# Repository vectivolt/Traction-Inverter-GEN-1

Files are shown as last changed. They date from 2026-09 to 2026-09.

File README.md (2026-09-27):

<p align="center">
  Traction Inverter GEN-1 — 220 kW · 800 V · SiC · ASIL-D-capable
</p>

<p align="center">
  
  
  
  
</p>
<p align="center">
  
  
  
  
  
  
  
  
  
  
  
</p>

<h3 align="center">
  A 220 kW-class SiC traction inverter for 500–850 V packs (800 V-class packs whose full-charge voltage stays ≤ 850 V) —<br/>
  engineered to be <b>economical</b>, <b>ASIL-D-capable</b>, and <b>buildable by any competent CEM</b>.
</h3>

<p align="center">
  <a href="#-schematics">Schematics</a> ·
  <a href="#-specifications">Specs</a> ·
  <a href="#%EF%B8%8F-system-architecture">Architecture</a> ·
  <a href="#-functional-safety-asil-d-concept">Safety</a> ·
  <a href="#-dc-link-discharge--checked">Discharge</a> ·
  <a href="#-bom--cost-analysis">BOM & Cost</a> ·
  <a href="#-manufacturing--sourcing">Manufacturing</a> ·
  <a href="#-verification-pipeline">Verification</a> ·
  <a href="#-getting-started">Build</a> ·
  <a href="#-roadmap">Roadmap</a>
</p>

---

## 🎯 What this is

**GEN-1** is a complete, netlist-verified schematic set + costed BOM for a four-assembly traction
inverter, generated from a single **tscircuit** source of truth:

> **Marine Series** (M8 · M10 propulsion cells, ferries to tugs) is a separate product line built
> on this design — see [`marine/README.md`](marine/README.md).

| Board | Domain | Contents | Parts |
|---|---|---|---|
| 🔴 **Power board** | HV (500–850 V) | 3× HIITIO `HCS600FH120D3C1` SiC half-bridges (EconoDUAL™ 3), 6× isolated gate-drive channels, dual gate-power flybacks, 2× isolated V<sub>DC</sub> senses, ASC buffer, HVIL loop | **274** |
| 🟡 **Cap bank** | HV (500–850 V) | Laminated-busbar assembly (not FR4 — it carries the 340 A bus): 16× 20 µF 1100 V film cans = 320 µF, entry lugs, 3× module DC tab pairs, discharge-board studs | **26** |
| 🟠 **Discharge board** | HV (500–850 V) | Bolt-on across the cap bank (XM3 pattern): always-on 66 kΩ passive bleeder + commanded active discharge (1.88 kΩ / 1200 V SiC), default-OFF opto control | **26** |
| 🔵 **Control card** | LV (KL30) | NXP **S32K396** lockstep MCU + **FS2633D** ASIL-D SBC, hardware gate-enable chain, ASC latch, resolver AFE, 3× hall-current AFE, 2× CAN-FD, vehicle interface | **219** |

### 🔗 Interboard links — every one explicit, both ends drawn + ERC-checked

| Link | Carries | Ends (sheet ⇄ sheet) | If it fails |
|---|---|---|---|
| **L1** 40-way harness | gate PWM ×6, faults/RDY, V<sub>DC</sub> + NTC feedbacks, EN/ASC, 15 V bias | `JIC` (power) ⇄ `JICC` (card) | every line default-OFF → gates held low |
| **L2** 4-way discharge link | V15 bias · `QDIS_CMD` · 2× GND | `JDIS` (power) ⇄ `JCTL` (discharge) | opto dark → active path OFF; 66 kΩ bleeder still discharges (57 s) |
| **L3** laminated busbar | DC bus (340 A<sub>rms</sub> class) | `JCBE*` lugs ⇄ HV entry · `JCB[UVW]*` tabs ⇄ module DC terminals · `JCBD*` studs ⇄ `JDCP/JDCN` (discharge) | bolted metal — torque-audited, HVIL opens the loop first |
| **L4** hall harness | 5 V per sensor + 3× current signals | `JLEM` (card) ⇄ 3× LEM HC5FW at the phase outputs | 100 k pull-downs (drawn since A.11): an open wire reads 0 V, outside the 0.2–4.8 V window → channel invalid |
| **L5** HVIL loop | interlock continuity through HV connector | `JHVIL` (power) ⇄ loop ⇄ card monitor | open = V<sub>DDIO</sub>/2 signature → controlled discharge |

Same net name on two sheets means **one net, joined only at the named connector/stud/tab** —
the rule is printed in every sheet's NET NAMING panel, and `erc-audit.mjs` asserts both ends
of every link pin-by-pin (the 40-way map alone is 80 assertions).
The design leans on three production references, read line-by-line: NXP **EV-INVERTERGEN3**
(control architecture, adopted almost verbatim), Wolfspeed **CRD300DA12E-XM3** (discharge +
gate-drive practice), and TI **TIDM-02014** (safety decomposition patterns).

> [!IMPORTANT]
> **Supply position:** the four power-silicon pieces (3 modules + discharge FET) come through
> a **direct HIITIO relationship**. Everything else on the BOM is LCSC-stocked or one
> ships-today DigiKey basket — verified line-by-line in two live sourcing sweeps.

---

## 📐 Schematics

The complete drawing set, one sheet per board — dashed functional sections, net-label-only
cross-section wiring, sheet index + net-naming + safety panels, self-identifying title blocks.

**➡️ Open the PDF set: [`boards/out-pdf/`](boards/out-pdf/) · Import into EasyEDA Pro: [`kicad5/Traction-Inverter-SHIP.zip`](kicad5/Traction-Inverter-SHIP.zip) · Open in native KiCad 5: [`kicad5/Traction-Inverter-KiCad5-native.zip`](kicad5/Traction-Inverter-KiCad5-native.zip) · Open in KiCad 10.0.6+ (the layout handoff: every symbol bound to a footprint in the shipped library): [`kicad/Traction-Inverter-KiCad-modern.zip`](kicad/Traction-Inverter-KiCad-modern.zip)** — three variants of the same sheets. EasyEDA's legacy importer ignores the symbol orientation matrix, so its variant carries a pre-mirrored library; native KiCad applies the matrix and needs the un-mirrored one (round 15, A13-R05); both are verified pin-by-pin with their consumer's placement rule. **Which KiCad reads which set:** the two legacy `.sch` sets are for KiCad 5–8; the `.kicad_sch` set ([`kicad/traction/`](kicad/traction/)) is for KiCad 10 (its schematics also open in KiCad 9, but the footprint library is the 10.0.6 file format, so the footprint-enabled handoff is KiCad 10 — round 23) — KiCad 10.0.6 loads the legacy sheets but resolves none of their symbols (its netlist has 0 components and its ERC flags every pin stub unconnected; its JSON report also prints each 200-mil stub as 0.0508 mm, which is 10.0.6 scaling every JSON coordinate by 1/100 for any schematic — the text report reads 5.08 mm). The `.kicad_sch` set is translated item for item from the same sheets and proved with KiCad 10.0.6 itself (`kicad-sch-verify.mjs`): ERC on every sheet, and a netlist export equal to circuit.json net by net.

| Sheet 1 — Power board (HV) | Sheet 4 — Control card (LV) |
|---|---|
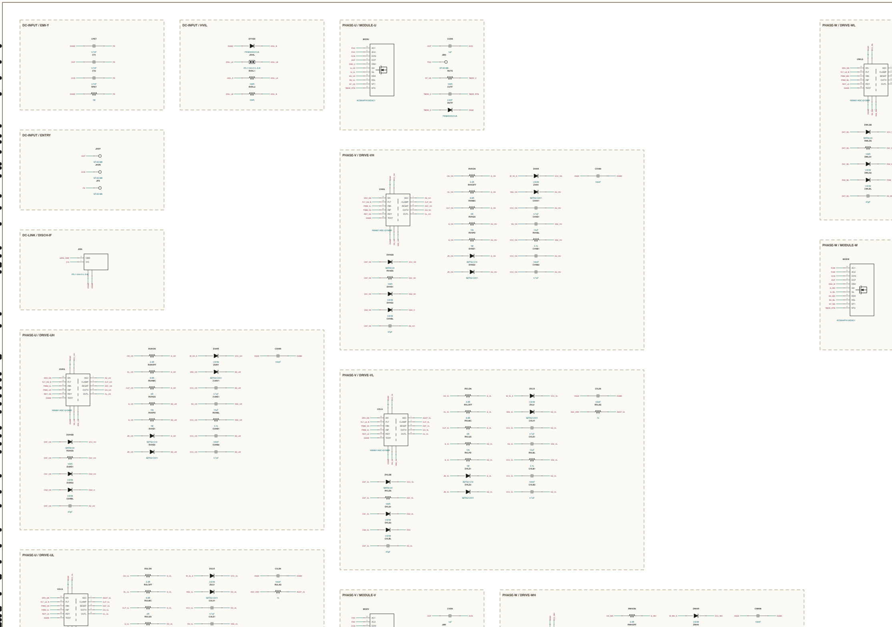
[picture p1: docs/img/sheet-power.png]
Power board sheet
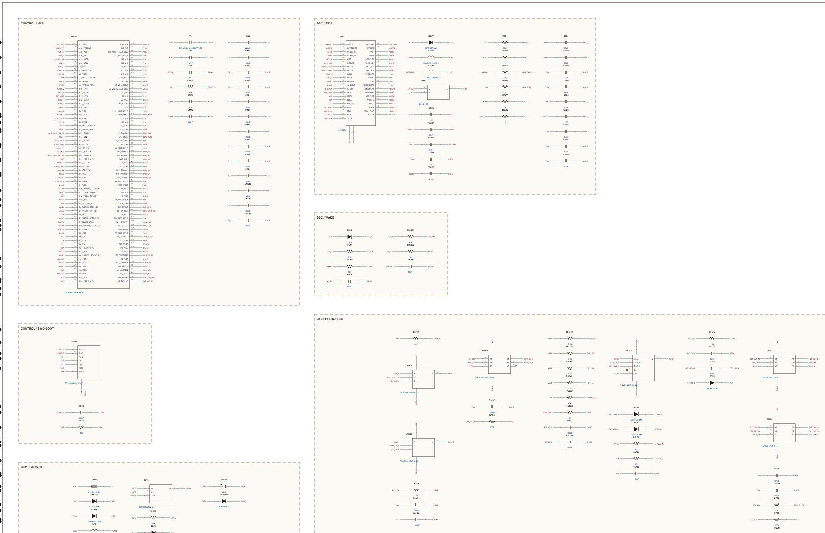
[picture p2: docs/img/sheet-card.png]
Control card sheet
|  |  |

| Sheet 2 — Cap bank (busbar assembly) | Sheet 3 — Discharge board (bolt-on) |
|---|---|
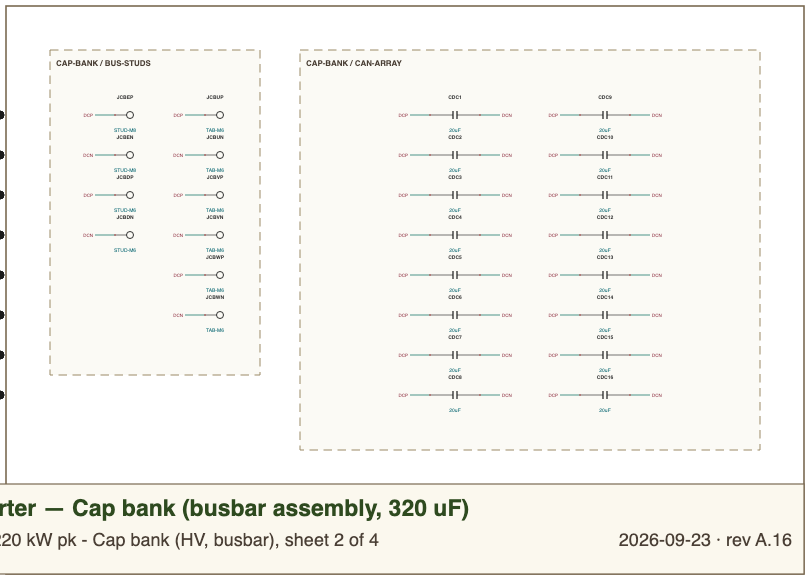
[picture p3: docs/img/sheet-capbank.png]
Cap bank sheet
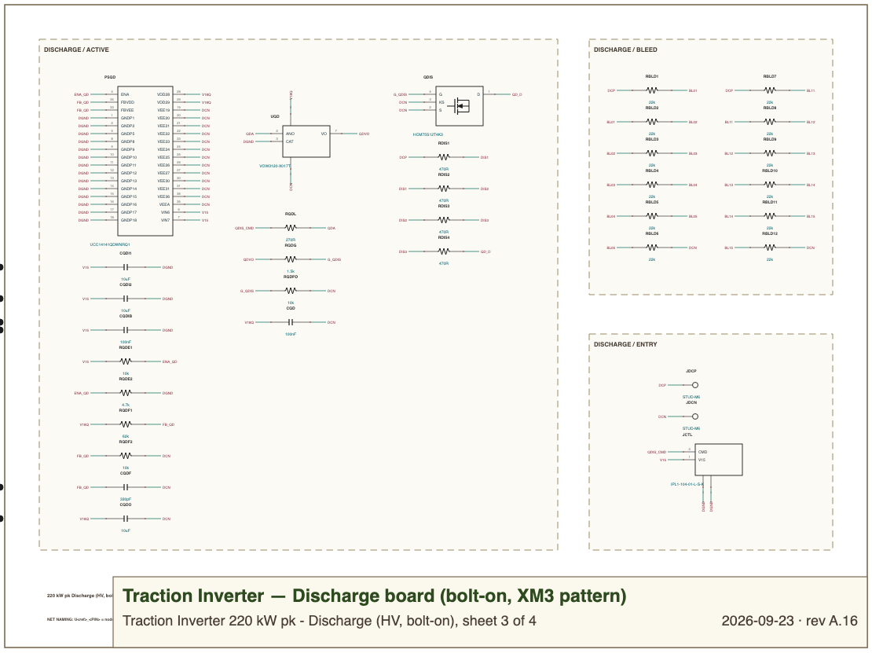
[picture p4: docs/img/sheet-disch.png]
Discharge board sheet
|  |  |

Every sheet carries its own review panels — the ASIL-D concept and the discharge verification
are printed **on the drawing**, so the schematic is never the only artifact a reviewer holds:

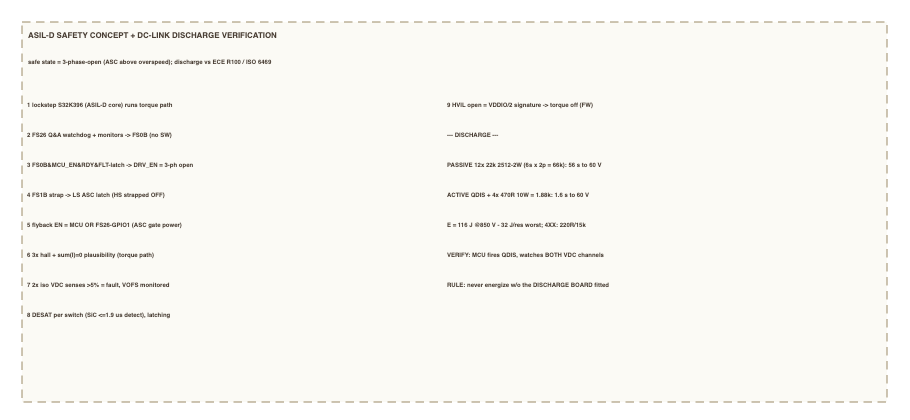
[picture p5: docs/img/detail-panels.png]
On-sheet panels: sheet index, net naming, ASIL-D safety concept + discharge verification


---

## ⚡ Specifications

<table>
<tr><td valign="top" width="50%">

### Ratings

| Parameter | Value |
|---|---|
| DC-link voltage | **500 – 850 V** (700 V nom) · 4XX SKUs **250 – 500 V** |
| Peak power | **220 kW** / 30 s from 654 V (168 kW at 500 V; 4XX 150 kW from 379 V) |
| Continuous power | **120 kW** from 656 V (4XX 90 kW) |
| Peak phase current | **340 A<sub>rms</sub>** (480 A pk) |
| Continuous phase current | 185 A<sub>rms</sub> |
| Semiconductor efficiency (continuous point) | **SiC 99.0 %** · **IGBT 98.6 %** |
| DC feed current | 314 A pk / 171 A cont |
| Switching frequency | **SiC** 8–10 kHz · **IGBT** 5 kHz |
| Motor type | 3-φ PMSM, resolver feedback |
| Cooling | Liquid coldplate @ 65 °C |
| Ambient | −40 … +85 °C |

</td><td valign="top" width="50%">

### Key silicon

| Function | Part | Grade |
|---|---|---|
| Power switch ×3 | HIITIO **HCS600FH120D3C1** (SiC) *or* **HCG600FH120D3E1EA** (IGBT) — same pads & pins | EconoDUAL 3 |
| Gate driver ×6 | **NSI6611A-Q1** 10 A iso, DESAT + Miller | AEC-Q100 |
| MCU | NXP **S32K396** lockstep M7 | ASIL-D |
| Safety SBC | NXP **FS2633D** | ASIL-D |
| V<sub>DC</sub> sense ×2 | **AMC1311B** reinforced iso | — |
| Phase current ×3 | LEM **HC5FW 900-S** hall | 900 A |
| Resolver driver | **ALM2402Q-Q1** | AEC-Q100 |
| CAN-FD ×2 | **TCAN1042HGV-Q1** | AEC-Q100 |

</td></tr>
</table>

<details>
<summary><b>📏 Sizing math (click to expand)</b> — why every number above closes</summary>

| Check | Calculation | Result |
|---|---|---|
| Max line-line voltage | V<sub>ll</sub> = 0.95 · V<sub>dc</sub>/√2 (linear SVPWM, 5 % reserve) | 470 V<sub>rms</sub> at 700 V |
| Power available | √(3/2) · 0.95 · V<sub>dc</sub> · 340 A · PF 0.85 | 235 kW at 700 V — 220 kW needs ≥ 654 V (FW-03) ✅ |
| Per-switch conduction, SiC peak | ½ · I<sub>rms</sub>² · R<sub>DS,hot</sub> = ½ · 340² · 5.7 mΩ (synchronous bridge) | 329 W |
| Per-switch switching + Q<sub>rr</sub> + dead time @850 V/10 kHz | DS energies at the drawn 3.3/6.8 Ω, ∝ V · I | 225 W |
| Per-switch total, 30 s peak / continuous | `loss-model.mjs` (SiC; IGBT build in `docs/variants.md`) | 554 W / 200 W → T<sub>j</sub> 125 °C (S4; 135 °C with no plate mass) / 90 °C ✅ |
| Voltage utilization | 850 V / 1200 V; turn-off overshoot is the DPT gate (S8) | 71 % ✅ |
| DC-link ripple current | I<sub>c,rms</sub> ≤ 0.65 · I<sub>ph</sub> (worst M/cosφ, Kolar) | 221 A pk (13.8 A/can) / 120 A cont |
| Link capability | 16 cans × 15.4 A (C3D, 10 kHz/70 °C) | 246 A ✅ |
| Stored energy @850 V | ½ · 320 µF · 850² | **116 J** |
| Gate power per switch (SiC) | Q<sub>g</sub> · ΔV · f = 1.09 µC · 20.5 V · 10 kHz | 0.22 W ✅ |
| Hall range | ±900 A vs 481 A pk | 1.9× headroom ✅ |

Full derivations: [`docs/design-basis.md`](docs/design-basis.md)

</details>

---

## 🏗️ System architecture

```mermaid
flowchart LR
  subgraph HV["🔴 POWER BOARD — HV domain"]
    direction TB
    DCIN["HV DC entry<br/>M8 studs + Y-caps + HVIL"] --> LINK["CAP BANK busbar assembly<br/>16× 20 µF/1100 V film = 320 µF"]
    LINK --> BLEED["Passive bleeder 66 kΩ<br/>57 s → 60 V"]
    LINK --> ADIS["Bolt-on discharge board<br/>66 kΩ bleeder · 1.88 kΩ + 1200 V SiC · 1.6 s"]
    LINK --> MU["MOD U<br/>600 A SiC ½-bridge"]
    LINK --> MV["MOD V<br/>600 A SiC ½-bridge"]
    LINK --> MW["MOD W<br/>600 A SiC ½-bridge"]
    GDU["2× NSI6611A-Q1<br/>DESAT · Miller · ±(15/−5.1) V"] --> MU
    GDV["2× NSI6611A-Q1"] --> MV
    GDW["2× NSI6611A-Q1"] --> MW
    FLY["2× gate-power flybacks<br/>UCC28C40 + 3× VGT12EEM each<br/>6 floating domains"] --> GDU & GDV & GDW
    VDC["2× AMC1311B iso V-sense<br/>independent dividers + bias"] -.-> LINK
    ASC["ASC buffer<br/>DCN-referenced opto"] --> GDU & GDV & GDW
  end

  subgraph LV["🔵 CONTROL CARD — LV domain"]
    direction TB
    SBC["FS2633D ASIL-D SBC<br/>VPRE·VCORE·VREF·LDOs<br/>Q&A watchdog · FS0B/FS1B"] --> MCU["S32K396<br/>lockstep M7 · eTPU · SWG · SDADC"]
    MCU --> SAFE["Hardware gate-enable chain<br/>FS0B ∧ MCU_EN ∧ RDY"]
    MCU --> RSLV["Resolver AFE<br/>SWG → MFB filter → ALM2402Q"]
    HALL["3× hall AFE<br/>LEM HC5FW 900-S"] --> MCU
    CAN["2× CAN-FD<br/>TCAN1042-Q1"] <--> MCU
  end

  MOTOR(("🌀 PMSM"))
  VEH["🚗 Vehicle<br/>KL30 · KL15 · CAN ×2<br/>resolver · motor temp"]

  MU & MV & MW ==>|"U · V · W<br/>340 Arms pk"| MOTOR
  SAFE -->|"40-way harness<br/>default-OFF"| GDU
  VEH <--> LV
  MOTOR -.->|resolver sin/cos| RSLV
```

<details>
<summary><b>🔌 One gate-drive channel in depth</b> (×6 on the board)</summary>

```mermaid
flowchart LR
  PWM["PWM_xH (IN+)<br/>PWM_xL (IN−)<br/>complementary pair =<br/>shoot-through lockout"] --> DRV
  EN["DRV_EN<br/>(hardware safety chain)"] --> DRV
  DRV["NSI6611A-Q1<br/>reinforced iso · 10 A"]
  DRV -->|"OUTH → 1.5 Ω"| G["Gate node"]
  DRV -->|"OUTL → 1.0 Ω"| G
  DRV -->|"CLAMP 0 Ω<br/>Miller clamp"| G
  G --> SW["SiC switch<br/>(½ of EconoDUAL)"]
  SW -->|"drain"| DS["DESAT chain<br/>BAT64-04 → 100 Ω → 2× US1M<br/>47 pF ≈ 1.5 µs blanking"]
  DS --> DRV
  BIAS["Flyback secondary<br/>rectifier + C5V1 zener split<br/>+15 V / −5.1 V vs Kelvin"] --> DRV
  DRV -->|"FLT# wired-OR · RDY wired-AND"| FB["→ MCU + safety chain"]
  G --- P1["10 k G-S bleed ·<br/>1 M HV pulldown at module pin ·<br/>18 V + 5V1 zener stack"]
```

Values carried from the GEN3/XM3 references; `R_g` tuned at double-pulse test.

</details>

---

## 🛡 Functional safety (ASIL-D concept)

The safe state is **3-phase-open**; above the motor's crossover speed it is **ASC** (active
short via the low side). The fast paths — watchdog → FS0B, DESAT → fault latch, the enable AND
chain, the ASC latch — are **hardware**; HVIL, V<sub>DC</sub> and ΣI plausibility are firmware
([`docs/firmware-contract.md`](docs/firmware-contract.md), including the fault × speed
safe-state matrix).

```mermaid
stateDiagram-v2
    direction LR
    [*] --> INIT : KL30 + KL15
    INIT --> RUN : FS26 WD happy · FS0B high<br/>MCU_EN high · RDY_HS ∧ RDY_LS
    RUN --> SPO : any of — WD fail → FS0B low ·<br/>DESAT latch · HVIL open ·<br/>VDC mismatch >5% · ΣI ≠ 0
    RUN --> ASC : overspeed + fault<br/>(MCU ASC_REQ or FS1B strap)
    SPO : SPO — 3-phase OPEN
    SPO : all 6 driver EN low (hardware AND)
    ASC : ASC — low-side SHORT
    ASC : latched · survives MCU reset ·<br/>SBC keeps gate power via GPIO1 OR-gate
    ASC --> SPO : speed below threshold · ASC_CLR
    SPO --> DISCHG : shutdown / crash / HVIL open
    DISCHG : ACTIVE DISCHARGE
    DISCHG : 850→60 V in 1.6 s · witnessed on BOTH V_DC channels
    DISCHG --> [*]
```

<details>
<summary><b>🔟 The ten hardware mechanisms (decomposition table)</b></summary>

| # | Mechanism | Independence argument |
|---|---|---|
| 1 | Lockstep **S32K396** (ASIL-D core) runs the torque path | — |
| 2 | **FS26 Q&A watchdog** + rail monitors → **FS0B** | Separate silicon, zero software |
| 3 | FS0B ∧ MCU_EN ∧ RDY **hardware AND** → all 6 driver enables | Discrete 74LVC1G11-Q100 gates |
| 4 | **FS1B strap → latched LS-ASC select** (HS strapped OFF) | SBC-commanded, survives MCU reset |
| 5 | Flyback enables **OR-gated (MCU ∨ FS26-GPIO1)** | SBC alone keeps gate power for ASC |
| 6 | 3× hall current + **ΣI = 0 plausibility** | 3rd channel = built-in redundancy |
| 7 | **2× isolated V<sub>DC</sub>** senses, >5 % ⇒ fault, shared offset monitored | Separate dividers, amps + bias; receivers share V5A, the ADC reference (monitored — A.6) |
| 8 | Per-switch **DESAT** (≤1.9 µs to detect on SiC, latching) → global latch delayed past the soft turn-off | Different technology vs halls |
| 9 | **HVIL** ladder — open = V<sub>DDIO</sub>/2 signature | MCU ADC (firmware, ≤100 ms) |
| 10 | **Default-OFF pulldowns** on every harness-floatable line | Passive |

> The architecture implements the NXP GEN3 / TI TIDM-02014 pattern. A formal ASIL-D *claim*
> additionally needs the ISO 26262 work products (HARA, FMEDA, DFA) — out of schematic scope;
> the hardware those analyses lean on is all present. In parts, the entire safety chain costs **₹37**.

</details>

---

## 🔻 DC-link discharge — checked

Both references ship only a passive bleeder; GEN-1 keeps that network **and** adds a
default-OFF active path for the ≤2 s crash case — then *verifies* it. The whole network rides
its own **bolt-on discharge board** (sheet 3 of 4) mounted across the cap-bank busbar
(sheet 2), the XM3 pattern: the stored energy and its bleeder are one assembly.

```mermaid
sequenceDiagram
    autonumber
    participant V as Vehicle / Crash signal
    participant M as S32K396
    participant Q as QDIS (1200 V SiC + 1.88 kΩ)
    participant C as DC link (320 µF · 116 J)
    participant S as V_DC senses ×2
    V->>M: shutdown / crash / HVIL open
    M->>Q: QDIS_CMD (opto, DCN-referenced, default-OFF)
    Q->>C: discharge @ τ = 0.60 s
    C-->>S: dV/dt on BOTH isolated channels
    S-->>M: 850 → 60 V in 1.6 s ✅
    Note over M,S: no dV/dt within 200 ms ⇒ stuck-off fault<br/>QDIS only with contactors open + 5 s timeout
    Note over C: passive 66 kΩ always fitted:<br/>57 s to 60 V with zero commands
```

| Path | Network | τ | 850 → 60 V | Stress per resistor |
|---|---|---|---|---|
| **Passive** (always on) | 12× 22 kΩ 2512 2 W, 6s×2p = 66 kΩ | 21.1 s | **56.5 s nom / 65.3 s worst** ✅ | 0.96 W (48 %) · 154 V worst-tolerance (77 % of 200 V) |
| **Active** (commanded) | 4× 470 Ω 10 W fail-open wirewound + SiC FET = 1.88 kΩ | 0.60 s | **1.57 s nom / 1.81 s worst** ✅ (≤2 s crash · 5 s R100) | 31 J worst pulse (≥100 J rated) · 213 V |

4XX SKUs use the same discharge PCB with 4 × 220 Ω and 12 × 15 kΩ (1.70 s / 88 s worst).

> [!WARNING]
> **Rule printed on sheet 1:** never energize without the passive bleeder network fitted.

---

## 📊 BOM & cost analysis

Four SKUs of the same boards, one parts-db (the sheets, BOMs and LCSC fields cannot
disagree, and every BOM fails if a printed value disagrees with its MPN) — platform and
business case: [`docs/variants.md`](docs/variants.md):

| SKU | Electronics BOM @1k | Ex-works unit | Per peak kW | Suggested price (35–40 % GM) |
|---|---|---|---|---|
| **8XX SiC** (HCS600) | **₹72,983** → [`bom.md`](docs/bom.md) | ≈ ₹1.17 L | ₹530/kW | ₹1.75–1.95 L |
| **8XX IGBT** (HCG600) | **₹47,483** → [`bom-igbt.md`](docs/bom-igbt.md) | ≈ ₹0.91 L | ₹415/kW | ₹1.35–1.55 L |
| **4XX IGBT** (HCG600, 150 kW) | **₹45,883** → [`bom-igbt4.md`](docs/bom-igbt4.md) | ≈ ₹0.92 L | ₹610/kW | per-kW for its segment |
| 4XX SiC (on request) | ₹71,383 → [`bom-sic4.md`](docs/bom-sic4.md) | ≈ ₹1.16 L | ₹775/kW | — |

602 components · 191 lines · zero unmatched · per-board CSVs alongside each BOM.

```mermaid
pie showData title Electronics BOM contribution (₹ @1k)
    "Modules 3× (SiC 54,000 / IGBT 28,500)" : 54000
    "DC-link film caps (16×)" : 4800
    "Hall sensors + AFE" : 2321
    "Gate-power flybacks" : 2225
    "MCU + clock + debug" : 1465
    "Everything else (16 subsystems)" : 4872
```

**The Pareto is extreme by design:** 19 components carry 84 % of the cost — concentrated in
*quotable, second-sourced* lines — while the ~470-part long tail is LCSC-basic jellybeans.
The complete 6-channel isolated gate drive is ₹656; the whole ASIL-D safety chain is ₹37.

<details>
<summary><b>📈 Full subsystem Pareto (21 rows)</b></summary>

| Subsystem | ₹ @1k | Share | Cumulative | Parts |
|---|---|---|---|---|
| SiC power modules | 54,000 | 77.5 % | 77.5 % | 3 |
| DC-link film caps | 4,800 | 6.9 % | 84.4 % | 16 |
| Hall sensors + AFE | 2,321 | 3.3 % | 87.7 % | 34 |
| Gate-power flybacks | 2,225 | 3.2 % | 90.9 % | 63 |
| MCU + clock + debug | 1,465 | 2.1 % | 93.0 % | 22 |
| Vehicle connector + protection | 785 | 1.1 % | 94.1 % | 6 |
| Gate drivers + networks | 656 | 0.9 % | 95.1 % | 120 |
| Discharge (active + passive) | 630 | 0.9 % | 96.0 % | 21 |
| Module snubbers | 540 | 0.8 % | 96.8 % | 3 |
| FS26 SBC + LV input + wake | 527 | 0.8 % | 97.5 % | 27 |
| V<sub>DC</sub> iso sensing + bias | 340 | 0.5 % | 98.0 % | 21 |
| Resolver AFE | 269 | 0.4 % | 98.4 % | 48 |
| Harness + pulldowns | 246 | 0.4 % | 98.7 % | 17 |
| LV power (prot + LDO + boost) | 236 | 0.3 % | 99.1 % | 24 |
| HV entry / Y-caps / HVIL / studs | 188 | 0.3 % | 99.3 % | 14 |
| ASC buffer | 139 | 0.2 % | 99.5 % | 7 |
| CAN-FD ×2 | 132 | 0.2 % | 99.7 % | 14 |
| Temps (module/board/motor) | 82 | 0.1 % | 99.9 % | 24 |
| V<sub>DC</sub> receivers (card) | 61 | 0.1 % | 99.9 % | 12 |
| Safety chain (EN/ASC/ILK) | 37 | 0.1 % | 100.0 % | 21 |
| Module NTC routing | 4 | 0.0 % | 100.0 % | 9 |

</details>

### 💰 Full unit cost @1,000 units

```mermaid
pie showData title Ex-works unit cost — ₹114.6k baseline (₹ @1k)
    "Electronics BOM" : 69700
    "Housing (CNC Al + anodize)" : 8500
    "Coldplate (FSW liquid)" : 6000
    "Busbars (laminated DC + phase)" : 6000
    "PCBs + PCBA" : 8400
    "HV connectors + coolant QCs" : 5200
    "Assembly + EOL test + coat" : 3200
    "Seals/TIM/harness/fasteners" : 3200
    "Yield + warranty 3%" : 3300
```

| | Low | **Baseline** | High |
|---|---|---|---|
| Ex-works cost / unit | ₹99.9k | **₹114.6k (~$1,380)** | ₹150.9k |
| ₹/kW | 454 | **521 ($6.3/kW)** | 686 |
| 1,000-unit build | ₹10.0 Cr | **₹11.5 Cr** | ₹15.1 Cr |
| Suggested ex-works price (35–40 % GM) | | **₹1.75–1.95 L (~$2,200)** | |

The two lines that move everything: the **HIITIO module quote** (47 % of unit cost) and the
**film-cap quote**. Comparable imported units (Cascadia CM350 class) sell at $4,000–7,000.
Detail + NRE table: [`docs/cost-rollup.md`](docs/cost-rollup.md)

---

## 🏭 Manufacturing & sourcing

Rev A.2 was a dedicated DFM pass, driven by **two live sourcing sweeps** (every specific MPN
checked on LCSC; misses re-checked on DigiKey/Mouser with LCSC alternates). Result — five
sourcing tiers, nothing single-channel outside the anchors:

| Tier | What | Lines | Channel |
|---|---|---|---|
| 🤝 **T1 Direct** | 3× SiC module + discharge FET | 4 | HIITIO (relationship in place) |
| 🏛 **T2 Franchise** | S32K396 · FS2633D · 3× LEM hall | 5 | NXP/LEM — **order first, longest lead** |
| 📦 **T3 DigiKey ships-today** | VGT12EEM ×6 · TE 770669-1/770680-1 · 10 W wirewounds · Murata MGJ2 ×2 (PO cert gate) · Coilcraft XAL ×3 · BUK7Y14-80E ×2 · NCV4276C ×3… | ~20 | one consolidated order |
| ✅ **T4 LCSC-verified** | ~60 lines *with live C-numbers* — incl. automotive grades of NSI6611A-Q1, AMC1311B, ALM2402Q-Q1, TCAN1042-Q1, TPS55340-Q1, OPA348-Q1, 74LVC1G11-Q100H, Faratronic link caps | ~60 | LCSC / JLC |
| 🧂 **T5 Jellybeans** | 0603+ passives, zeners, SS34, 2N7002… | ~440 | LCSC basic |

```mermaid
flowchart LR
  A["SMT 3 PCBs<br/>~750 placements · AOI"] --> B["Selective/wave THT<br/>studs · xfmrs · TO-247 · axials"]
  B --> C["Conformal coat card"]
  C --> D["CAP-BANK assembly<br/>16 cans onto laminated busbar"]
  C --> E["Modules → coldplate<br/>torque + TIM verify"]
  E --> F["Power PCB onto module pins<br/>(solder/press-fit per HIITIO dwg)"]
  D --> G["Busbar → module DC tabs<br/>+ DISCHARGE BOARD bolted across"]
  F --> G
  G --> H["Harnesses · lid · seal"]
  H --> I["EOL: hi-pot · discharge-time ·<br/>LV functional · B2B spin test"]
```

<details>
<summary><b>🔧 The seven DFM design changes (running log)</b></summary>

| # | Change | Why | Effect |
|---|---|---|---|
| 1 | Flyback controller **NJW4140 → UCC28C40DR** + 2-transistor default-OFF enable clamp | Nisshinbo part had 0–2 pcs on LCSC; the C43 grade cannot start at 9 V crank (F31) | Also **caught a latent bug**: the aux-only VCC could never start — trickle-start added |
| 2 | DC link **8× 40 µF → 16× Faratronic 20 µF/1100 V** (C2840809) | No 40 µF/1100 V can exists on LCSC in any brand | **−₹2.8k**, better ripple spread; TDK B32778 stays drop-in alt |
| 3 | Bleeder **9× TE CRGP (500 V specialty) → 12× generic 22 k 2512 2 W** 6s×2p (66 kΩ; the first cut, 10× 27 k 5s×2p, put 92 % of a 2512's 200 V working on each part) | TE part is TTI-only in volume | 154 V/resistor = 77 % of the 200 V working — any vendor builds it (dfm.md §2 item 3; boards/discharge.tsx RBLD1–12) |
| 4 | Resolver driver **confirmed ALM2402Q-Q1** (LCSC C544754) | Sweep found the GEN3-exact part in stock | No redesign |
| 5 | **Value consolidation** 4.99k→5.1k · 49.9k→51k · 12.1k→12k · 0402→0603 | Fewer feeders, JLC-basic, easier rework | Firmware-calibrated scalings unaffected |
| 6 | Vehicle connector → **TE 770669-1** 23-pos AMPSEAL header + 770680-1 plug | 776231-1 turned out to be the **35-pos** header (its own TE drawing, F60) | DigiKey-stocked, sealed automotive |
| 7 | Flyback switch **BUK9Y14 → BUK7Y14-80E**; clamp TVS SMAJ13A; both 10 µH → one XAL4040-103 line | Logic-level ±10 V gate was illegal at the 11.8 V drive (F56) | Same LFPAK56; zener now dark in normal operation |

Full plan incl. layout-phase DFM rules and proto-vs-production grade policy: [`docs/dfm.md`](docs/dfm.md)

</details>

---

## 🔬 Verification pipeline

Everything on this repo is **generated and gated** — the drawing set ships only at 100 %.

```mermaid
flowchart LR
  TSX["boards/*.tsx<br/>tscircuit source of truth"] -->|tsci build| CJ["circuit.json<br/>netlists"]
  CJ -->|pages.mjs| PG["section payloads<br/>21 functional pages"]
  PG -->|kicad5-gen.mjs| SCH["KiCad-5 sheets + lib<br/>skyline-packed sections,<br/>panels, title blocks"]
  SCH -->|kicad5-verify.mjs| V{"geometric re-derivation<br/>vs design intent"}
  SCH -->|kicad-sch-gen.mjs| KS[".kicad_sch set<br/>(KiCad 10)"]
  KS -->|"kicad-sch-verify.mjs<br/>(kicad-cli ERC + netlist)"| KV{"KiCad's own netlist<br/>vs circuit.json"}
  KV -->|"684 parts · 422 nets<br/>0 differences"| OK
  KV -->|any difference| FAIL
  V -->|"1717/1717 pins · 0 overlaps<br/>0 floating labels"| OK["✅ gate"]
  V -->|any mismatch| FAIL["❌ exit 1"]
  OK -->|kicad5-print.mjs| SVG["print-grade SVG"]
  SVG -->|"sheets-to-pdf.mjs<br/>(headless Chrome)"| PDF["📄 PDF set"]
  CJ -->|bom-gen.mjs| BOM["📋 bom.md + CSVs<br/>same parts-db as the sheets"]
```

Four independent verification layers — each with its own tool, none trusting the others:

| Layer | Tool | What it proves | Result |
|---|---|---|---|
| Sheets ⇄ netlist (geometry) | `kicad5-verify.mjs` | every drawn pin lands on its intended net — in BOTH shipped variants, each with its consumer's placement rule (EasyEDA import: raw offset; native KiCad 5: orientation matrix applied) | **2057/2057 · 100 % × 2** (the MCU by physical ball since A.13; ball-number and matrix mutations detected) |
| Sheets ⇄ KiCad (the tool itself) | `kicad-sch-verify.mjs` + KiCad 10.0.6 `kicad-cli` | the `.kicad_sch` set as KiCad reads it: ERC on every board sheet and the root (no dangling label or wire end, no unconnected pin, every symbol resolved, no duplicate reference); KiCad's exported netlist equals circuit.json — same components, same net names, same REF.pin in every net, the MCU on its manifest balls | **684/684 components · 422/422 nets · 0 differences** (a mirrored MCU — ERC-clean in KiCad! —, two swapped balls, the legacy harness numbering and a duplicated reference all detected) |
| Netlist ⇄ intent (structure) | `erc-audit.mjs` | pairing, chain topology, polarity, rails, floats, a lock-in per fixed finding | **954 checks · 0 fail** |
| Numbers ⇄ physics (worst case) | `design-verify.mjs` + `loss-model.mjs` | losses, thermal, envelope, discharge, protection timing, tolerances — **every SKU** | **132 PASS · 24 WARN · 0 FAIL** (each WARN names its bench/vendor gate) |
| Circuits ⇄ time/frequency domain | `sim-verify.mjs` | S1–S10: flyback start-up (cycle-by-cycle), boost Bode, SVPWM ripple, 30 s thermal per SKU, discharge ODE, current-loop PM per f_sw, overshoot budget, DESAT timeline, ASC hold-up | **23 PASS · 6 WARN · 0 FAIL** → [simulation-report](docs/simulation-report.md) |
| BOM ⇄ netlist (values) | `bom-gen.mjs` | every class MPN encodes the value the BOM prints; nothing is published unless the whole set validates | **0 mismatches, 4 SKUs** |

### 🔍 The review campaign — eight external rounds, every claim verified at the source

An independent reviewer ran five adversarial rounds against the released PDFs. The working
rule throughout: **no fix without primary-source verification, no rebuttal without evidence**
— every claim was checked against the manufacturer datasheet (winding diagrams read at
300 dpi where the dots decided it) before a single edit. Findings log **F1–F134, all closed**;
each round's full narrative lives in [`docs/design-basis.md`](docs/design-basis.md) §11.
Round six (46 findings) is answered line by line in
[`docs/review-A6-disposition.md`](docs/review-A6-disposition.md), and round seven (24 findings)
in [`docs/review-A7-disposition.md`](docs/review-A7-disposition.md), round eight (12 findings plus a 23-item cross-check of the fixes) in
[`docs/review-A8-disposition.md`](docs/review-A8-disposition.md), round nine in
[`docs/review-A9-disposition.md`](docs/review-A9-disposition.md), and the A.9 schematic rechecks, with their round-11 closure, in
[`docs/review-A10-disposition.md`](docs/review-A10-disposition.md), round twelve (63 findings across two
whole-system reviews) in [`docs/review-A11-disposition.md`](docs/review-A11-disposition.md), and the round-13
rechecks with the production closure (MCU ball map, barrier parts, connector) in
[`docs/review-A12-disposition.md`](docs/review-A12-disposition.md), and round fourteen (three reviews of the A.12
push: the pin-freeze errors, the firmware sequencing/clock/retention defects, the analog terminal-fault paths) in
[`docs/review-A13-disposition.md`](docs/review-A13-disposition.md), and round fifteen (three rechecks of A.13: the
exciter clamp topology, the native-KiCad export convention, the low-speed contactor loss) in
[`docs/review-A14-disposition.md`](docs/review-A14-disposition.md), and round sixteen (three rechecks of A.14: the
exciter amplitude corners and planes, the fault-model interpretation, the acquisition contracts) in
[`docs/review-A15-disposition.md`](docs/review-A15-disposition.md). Every contested number was
recomputed by an independent second model.

| Round | Release | Fixed | The headline catches |
|---|---|---|---|
| Self campaign | A.3 | 18 defects (F1–F36) | a gate supply that could never start; ASC drive over the driver's GND2+6 V abs max; discharge string missing the crash corner |
| Review 1 | A.4 | 10 (F37–F46) | **transformer secondary phasing** (forward-mode ≈35 V into +22 V-abs gates), DESAT clamp direction, raw KL15 into the MCU, unsourced gate-power feeds, hardware fault latch added, every symbol rebound to real package pins |
| Review 2 | A.4.1 | 5 (F47–F51) | **AMC1311 IN/SHTDN swapped on both channels** (inputs grounded), FS26 TRKIN was the VREF supply — not a ground-able spare, TPS55340 pin 5 is SYNC (7 V abs), V15 post-regulator vs boost pass-through |
| Review 3 | A.4.2 | 6 (F52–F57) | FS26 buck passives to Table-106, **CAN chokes wound 1-4/2-3** (CANH crossed onto CANL), ALM2402 behind its own LDO, **BUK7Y14-80E** (±20 V gate) |
| Review 4 | A.4.3 | 2 (F58–F59) | LCOR value/MPN/BOM/OTP agreement, UB15 compensation network (was ~0° screening margin) |
| Review 5 | A.4.4 | procurement | real MPNs bound; **RECOM R15P05S rejected** — 6.4 kV is a 1 s test, insulation grade *basic*; FS26 OTP table pinned (§8a) |
| Docs audit | A.5 | 3 (F60–F62) | JVEH rebound to the true 23-pos AMPSEAL **770669-1** (the TE drawing proved 776231-1 is 35-pos); QA01C rails read as **+20/−4 V** (the base part's sheet — corrected to the fitted QA01C-18, +18/−3 V, in A.9) — clamps re-verified |
| Review 6 | A.6 | 14 (F63–F76) | S8 overshoot **1000× unit error** (SiC turn-off now 6.8 Ω, DPT-gated); SiC conduction formula 2.4× low; IGBT SC is **6 µs** not 10 (blanking 82 pF); gate supply **never started at 9 V** (0.4 V UVLO hysteresis — 47 µF + 18 V clamp); BOM MPNs that would have re-created F40/F52; proposed "fault-dominant latch" **rejected** (deadlocks the NSI6611 FLT reset) — one-shot clear + soft-off delay instead |
| Review 7 | A.7 | 13 (F77–F89) | RC timing nodes into non-Schmitt LVC inputs at **63,500 ns/V** (Schmitt buffer); **ASC entry had no break-before-make** (12 nF LS delay; the MCU path holds ASC as PWM-ASC with EN high, because the NSI6611 honours DESAT over ASC only then — found by the round's own cross-check); flyback **locked out at high KL30** (own sense rectifier); FS1B loaded past its V_OL and FAULT_OUT made sink-only; 25 V caps on a 33 V node; ASC opto under its guaranteed turn-on current (self-found); +₹57/unit |
| Review 8 | A.8 | 16 (F90–F105, incl. its cross-check) | **a DESAT during latched ASC left the healthy low sides on** — the faulted driver holds itself off (NSI6611 Fig. 8.11) but only a ₹5 AND gate (ASC = latch AND no-FLT) guarantees SPO on every path; last slow latch preset buffered (FLT diode-OR now Schottky for the Schmitt threshold); discharge opto under-driven like the ASC one; boot self-test masked by RDY; FAULT_OUT battery-short clamp moved off the logic rail; atomic BOM publish; S4 junction path made static. Cross-check of the fixes: FW-15 always clears ASC, FW-16 on measured no-HV conditions with FS_GPIO1 and FLT-injection steps, dead-buffer pulls, 261 Ω LEDs inside 10–15 mA, B5V6 clamp, discharge header V15-GND-CMD-GND, ERC locks by net and MPN; +₹18/unit |
| Review 9 | A.9 | 14 (F106–F119, incl. its cross-check) | **the ASC/discharge bias modules were modelled from the wrong datasheet** (QA01C-18 is +18/−3 V, not +20/−4 V) — timing re-derived, discharge gate given a 1.5 k divider; **FLT/RDY pulled above the drivers' VCC1 rating** — pull-ups moved to V5GD on a harness pin; self-test energy-limited; RFS4 made anti-surge; self-found **≈150 mA parking drain** removed with one card-side P-FET. Cross-check of the fixes: V5GD read on an ADC pin (a dead V5GD faked a 0 V bus), harness re-laid for both dual-row numberings, resolver LDO sleeps too, QLVS slew-limited, DESATs kept in NVM; +₹29/unit |
| Review 10 | A.10 | 3 (F120–F122) | schematic-only rechecks of A.9 kept every correction; **RDY lines drove the AND gates at 20–100 ns/V against a 10 ns/V limit** — third Schmitt buffer (reverses a round-7/8 rejection); RASCG given a 0.33 W part; sheet and wording fixes; +₹11/unit |
| Review 16 | A.15 | 7 (F167–F173) | three rechecks of the A.14 push — all right: the SWG low corner through the series losses gave 6.34 V pp at the winding (exciter gain raised, 24 k → 28 k; FW-10 setpoint 7.2 V pp defined at the monitor plane with SWG-headroom and slew checks; planes documented); the back-drive row had read one RC time constant as the end of the pulse (exponential model, OPEN pending the diode envelope); **the exciter TVS is now unidirectional (SMCJ8.5A)** so a negative fault is carried by its forward diode instead of the amplifier's; the TVS-energy PASS rested on an extrapolated 20 ms allowance (conditional now, source impedance ≥ 0.27 Ω to allocate); the /33X PTC holds 70 mA at 85 °C (not 90); **firmware:** failed phase-ADC triplets stamped an uninitialised timestamp, resolver validity never expired without new blocks, and one SIN-DMA heartbeat tagged all three SDADC channels fresh — deterministic acquisition contracts, a per-tick frame-age policy and a coherent-frame API Same round, on instruction: the BOM furnished — every timing/filter/rail capacitor bound to a dielectric/voltage/size class, the last placeholders (KL15 polyfuse MF-MSMF010/60X, automotive beads, Samtec IPL1 link/HVIL headers, VY2 chassis cap) bound with archived sheets, and a drawn-size gate in the BOM generator. Marine forked at A.15 (86 PASS · 22 WARN · 0 FAIL). |
| Round 24 | A.23 | 3 (F240–F242) | **four rechecks of the A.22 push (`review-A23-disposition.md`), all three findings confirmed — one of them a wrong disposition of ours:** the S32K39 data sheet's SDADC table (Rev. 3 Table 38, in our archive and in our own extracted-parameters file) requires the SDADC reference within ±25 mV of its supply, and the round-23 row had judged the general +100 mV note and called the figure absent while the references sat on the FS26's separate VREF, matched to the SDADC-supply LDO only within ±1 % → every non-R2R reference group moved onto V5A itself, the node of VDDA_SDADC and VDD_HV_A (NXP's GEN3 arrangement), the ratiometric loads with it, the FS26 VREF kept for the R2R ladder alone with CSB5 2.2 µF holding its capacitance window by itself, the SAR's absolute scale re-budgeted at the LDO2's ±1.75 % (F240, no new part, a layout rule in the handoff); **firmware:** a stopped temperature ADC channel stayed valid forever because the caller discarded the acquisition timestamp → a three-state freshness contract (new / held / expired) with a hold-time CAL and the other slow consumers audited (F241); the inductance-map check bounded L but not the flux slope, and the ripple limiter looked only at its interval's ends → a positive flux slope required in every segment and the limiter evaluating the interior breakpoints, proved against a fine-scan oracle (F242); the R2R separation, the SMT SWD land, the torque solver (two independent fixtures: 8 four-quadrant cases, 20 000- and 4 049-case screens, zero violations) and the BOM intro confirmed by the reviewers' own runs; two more firmware defects found and fixed on the way (F243 the temperature-rate latch overwritten by an open/short sample, F244 the V_DC channels' sticky expiry); 444 tests / 5199 checks / 0 failed, TI_FW_ID 0x0A0F0016, 82 DTCs; ₹0/unit |
| Round 23 | A.22 | 26 (F214–F239) | **three rechecks of the A.21 push, one carrying five findings we had never received:** the R2R (sine-wave DAC) reference sat on the shared VREF5 against the S32K39 data sheet's note 8 → its own RC-isolated branch at ball A9 (RR2R 10 Ω + 1 µF + 100 nF, ≈ ₹0.6; F214); the SWD header is a SURFACE-MOUNT Samtec FTSH -DV and was bound to a through-hole land → the drawn SMT land and a mounting-technology lock in the library generator (F215); the footprint library is KiCad 10.0.6 format and was wrongly mirrored into the KiCad 5 sets → KiCad 10 is the footprint-enabled handoff, the KiCad 5 / EasyEDA sets carry names only (F216); **firmware: the torque solver could return a current vector representing ≈ 2× the requested torque in field weakening on a salient motor (i_d deepened without recomputing i_q; the witness checked voltage only) → torque, voltage, current circle and demagnetisation solved together on the torque curve with a postcondition before every return, the applied torque reported in the status (INV_STATUS 20 B), 300 tests / 2802 checks / 0 failed at that point, 8 mutations caught (F217); the no-LUT MTPA fallback now converges (F218)**; the BOM intro follows the SKU (F219); the review's ± 25 mV reference-tracking figure is not in the archived data sheet — a verifier row (50 mV against the +100 mV window) and VR-34 to NXP close it, VR-35 asks for the R2R reference current (F220). **Also this round, on the user's instruction — the VESC program:** the VESC firmware and VESC Tool sources archived as GPL-3.0 reference only (`docs/reference/vesc/`), a two-sided feature matrix (`docs/firmware-vs-vesc.md`) whose ranked gaps were closed in the same round — FW-38 signed field update (Ed25519, anti-rollback, ISO-TP transfer), FW-39 interlocked motor self-commissioning, FW-40 UDS diagnostics (0x19/0x22/0x2A/0x14 over ISO 15765-2, 80 DTCs), FW-41 fault-triggered waveform capture, FW-42 overspeed, FW-43 run-time statistics, FW-44 key-on offset adoption — and a closed-loop simulator bridge that ran the firmware against a plant for the first time and found twelve defects (F221–F232: uncontrolled diode regeneration once the back-EMF passes the link below n_x, a temperature-rate check tripping on one ADC code, unslewed torque steps, six never-set DTCs, ASC chosen at 2 000 rpm after a resolver loss, the demodulator's time centre, the resolver debounce bypass, an NVM CRC blind to torn records …), all fixed with fail-before/pass-after tests; 402 tests / 4707 checks / 0 failed, TI_FW_ID 0x0A0F0015, CAL layout 3 (4 after the extension); and **Traction Tool** (`tool/`), an offline Qt 6 bench/service application with the simulator, replay and CAN transports — see `docs/tool-stack-decision.md`. **Extension ("why not done / implement them"):** the suite runs on the Cortex-M7 instruction set with the target compiler under QEMU (T-59; test-code defects the target compiler caught, host rounding matched to the target, the 64-bit divide out of every ISR path with a link-time guard — F235–F237); every commissioning routine proved against the bridge, which found the bridge never loading a committed record (F233); the CAN transport proved against the firmware over a virtual bus — it had no ISO-TP reassembly (F234) — and the FW-38 update end to end over both transports, which found a UDS escape frame every non-diagnostic service dropped (F238) and a bridge without a boot record (F239); matrix gaps 8 and 10 closed as capabilities (FW-45 saturation tables, FW-46 cogging feed-forward; the maps are dyno measurements T-57/T-58; CAL layout 4); the licence items closed (corresponding source shipped, Qt attributions generated); the root of trust reported (DID 0xFD23); the Firmware page transfers images; 421 tests / 4937 checks / 0 failed; ₹0.6/unit |
| Round 22 | A.21 | 5 (F209–F213) | **three rechecks of the A.20 push — all right, one MINOR of theirs — and the user's question: why is the schematic not furnished for PCB layout?** The reviewers' NOT READY verdicts are bench, target and vendor evidence that needs a built board; the circuit carried no open defect. What was unfurnished was the handoff: every KiCad symbol carried a bare package code and no footprint library shipped, so Update PCB from Schematic could not run for any of the 686 components — **closed: `traction.pretty` (45 patterns copied verbatim from KiCad 10.0.6 with provenance, 18 drawn from the archived datasheets — the EconoDUAL 3 module, UCC14141 DWN-36, AMC1311B DWV, VOW3120, VGT12EEM, Samtec IPL1 ×3, TE 770669-1, the Faratronic can, Bel 2410 fuse, TDK ACT45B, the SQP10 at its real 55.88 mm pitch, onsemi SMA flat-lead, Kyocera 2-pad crystal, the FS26 and ALM2402 lands, LEM HC5FW), `fp-lib-table` and per-board project files in every set and zip, F2 = `traction:<name>` on every on-board symbol (the LEM sensors off-board), the generator refuses an unbound part, the KiCad proof judges footprint links and every pin number on a pad** (F210); the proof and a datasheet pin audit of 31 part groups caught the NCV4276C regulators coded as 3-lead DPAKs (5-lead only, F211), the ALM2402 and TPS55340 thermal pads with no symbol pin (pins 15/17 on ground, F212) and the two-terminal crystal on a 4-pad pattern (F213); the QP §0.2 DUT/FW/VAL baseline and the last 0x0A0F0011 mentions brought to A.20+ / 0x0A0F0013, the README bleeder row, MCU ball count, VR-17, the RFS4 fault-hold row and the dfm fillet rule corrected (F209); **[`docs/layout-handoff.md`](docs/layout-handoff.md)** is the layout engineer's entry point; ₹0/unit |
| Round 21 | A.20 | 1 (F208) | **three rechecks of the A.19 push — all right, nothing on the circuit:** F205–F207 close in all three (the alternates in the emitted CSVs, the firmware ID, the firmware trees identical to A.18; the diversion figures reproduced independently — 9.02 V / 3.84 A / 34.8 A at 24 V, 36.1 A at 35 V, τ 59.9 µs, 0.231 mC; the 4XX discharge 1.47 s at 220 Ω against 3.07 s at 470 Ω); one MINOR documentation defect — gate ㉘ still quoted IR-16 ≥ 0.29 Ω for the 35 V double event where IR-16 says 0.37 Ω (42.6 A against 37.9 A at the cold corner) — confirmed and broader than reported: the same round-18 figure sat in QP-RX-04's own step-3 fixture instruction, and 8.5 V-era figures remained in the QP's post-trip pass criterion (0.6 / 0.3 / 1.5–3.8 W), its Marine cross-reference (5.2 / 8.3 W, the uncapped formula), QP-RX-05's rail figure, VR-33's envelope (4.8 A / 0.28 mC / ≤ 11 V), this gate's trickle and sweep resistances, the card comment and the RSX BOM description (4.8–4.9 A) — every live figure now reads the 7.0 V-class value from the shared model with the old one marked; ₹0/unit |
| Round 20 | A.19 | 3 (F205–F207) | **three rechecks of the A.18 push — all right, nothing on the circuit:** the resolver-origin and high-current findings close in all three; two BOM-metadata errors of ours corrected — the exciter TVS alternate still called the 8.5 V part "same electricals" after the class change (→ the plain SMDJ7.0A, the 8.5 V class excluded from the qualification) and the 4XX discharge row carried the 8XX 470 Ω alternate (→ SQP10AJB-220R; four 470 Ω would take 3.1 s to 60 V against 2 s) — each with an ERC lock; the target checklist's firmware ID brought to 0x0A0F0013; every 8.5 V-era figure re-derived from the shared model at the IR-16 allocations, including the back-drive row that was still evaluated at 0 / 0.29 Ω; ₹0/unit |
| Round 19 | A.18 | 4 (F199–F202) | **three rechecks of the A.17 push — all right, plus one of our own:** the PTC-current row had been evaluated at 24 V while IR-16 allowed 26 V (41.6 A cold at 26 V / 0.05 Ω) — every permitted voltage now, minima at the verifier's own 5 % margin, rounded up (IR-16 0.09 / 0.33 / 0.25 Ω — the 8.5 V-class interim values, superseded within the round); the ≥ 8 A TVS-energy PASS rested on an I⁻² trip-time law no sheet states — an explicit assumption and a WARN closed by the measured clearing waveform (QP-RX-04 step 2 release criterion, VR-16); the resolver ring had anchored its clock on the first completion callback, so an over-budget or constantly-late callback became the reference — **FW-35 rewritten: the origin is the SWG start on the microsecond timer**, every completion judged absolutely, resync from the clock with per-channel slot checks, a synchronized restart on ambiguity; the round-18 window row had printed 1–200 Ω for a criterion error (14–83 Ω at 24 V); the exciter fault model is one shared module, run for the **Marine port at the ship's voltages** — the kit's 12 V rail is the platform's worst sustained-short case (5.2–8.3 W in the TVS by the uncapped 8.5 V-class formula — 2.0–2.5 W at the 7.0 V class after F203/F204), a kit-loom requirement and QP-MA-11 carry it; **one zero-cost part change — TVSEP/TVSEN → SMDJ7.0A-HRA** (the Opus cross-check showed the coupled island cannot hold the 8.5 V class below 148–171 °C at a parked 12 V battery or the Marine rail, because the tripped PTC's trickle scales with V_BR/(V_S − V_BR); the 7.0 V class halves it and stays ≤ 132 °C coupled, keeps every dark condition with ≥ 2.4 V margin, and costs +0.043 Ω on each IR-16 allocation — 0.08 / 0.14 / 0.37 Ω, an OEM statement now needed at 24 V); 290 tests / 2705 checks / 0 failed in three build flavours, 108 failing on the pre-fix ring, 16 mutations caught, TI_FW_ID 0x0A0F0013; ₹0/unit |
| Round 18 | A.17 | 9 (F190–F198) | **three rechecks of the A.16 push — all right, two under-stated:** the diversion Schottky sat on the protected node so its charging loop bypassed the resistor its own model divided by (27–99 A instead of 5 A) — moved to the amplifier node, zero parts; **the generic diode cell numbered the anode as pin 1 on all 35 two-pin diodes** against the parts' pinning tables and KiCad's footprints — one shared cell, ERC-locked on every board; the NCV4276C 40 V output rating withdrawn as reverse-current evidence (release gate + VR-33); the exciter TVS/PTC rows recomputed at their worst corners (the 20 ms bound holds only for a direct short; the 9 J point is ≈ 5.3 J rectangular) and the cross-check's own finding — a sustained short to the normal battery with the ECU asleep leaves 1.5–3.8 W in the TVS after the PTC trips (8.5 V class; 0.9–1.7 W since round 19) — closed by a layout rule, a bench sweep, IR-42 and VR-17; RSX an anti-surge 0.5 W part; firmware: fresh samples no longer aged against the earlier ISR clock, cadence-locked resolver frames with a servicing deadline and self re-acquisition, the chain-latency sign, plus three self-found instances of the same class (task liveness, the FW-15 recovery timer, the PWM-ASC dead-time reference) — 278 tests / 2534 checks / 0 failed in three build flavours, 98 (+2) failing on the pre-fix tree, 16 mutations caught; +₹2/unit (the anti-surge RSX pair) |
| Round 17 | A.16 | 16 (F174–F189) | **gap closure** ("close all gaps", "feel free to upgrade") — every WARN/OPEN/TODO became a design change, a numbered interface requirement (IR-01…41), a vendor request with acceptance criteria (VR-01…32) or an executable procedure (92 QPs): rated back-drive diversion diodes, 3 kW AEC-Q101 exciter TVS, the LV entry re-designed as let-through for ISO 16750-2 test B (pulse 1 was avalanching the reverse Schottky, the 2023 26 V jump start opened the old TVS, the input polyfuse was undersized at 9 V), RFS4 1206, stale rows recomputed, the discharge resistor no-flame statement cited, a KiCad 9/10 set proved by KiCad 10's own netlist (which exposed a harness pin-numbering defect in the legacy sets), firmware: all 35 open contract items closed, FS26 watchdog cadence 2.0 ms (was at the window edge), ASC-exit release wait, FW-31/32/33, a 39-row silicon checklist; 104 datasheets. Marine forks at A.16 (86 PASS · 22 WARN · 0 FAIL; the M10 stuck-ON wording corrected to 103 W per resistor on the SQP no-flame statement) |
| Review 15 | A.14 | 8 (F159–F166) | three rechecks of the A.13 push — all right: **the round-14 exciter TVS sat on the connector node, so a harness fault fed it without passing through the PTC** (moved to the protected node, 2.2 Ω series resistor, monitor tap moved, ERC graph-cut check); the "no back-drive" argument did not cover VEXD absent/cranking or negative faults (modelled, bench gate ㉘ extended); the PTC was bound to 1206 (it is 1812; /33X variant, hot hold 0.09 A); NTC_A's new ball is a standard-class ADC input but the target map said precision (generator now emits the full triple); **the shipped KiCad files were the EasyEDA-import variant only — read in native KiCad the mirrored library put H5 on FLT_CLR_M** (a `traction-native/` variant is now generated and both are verified with their consumer's placement rule, matrix mutation detected); the contactor-loss detector ignored low speed and left torque permission for the same invocation (firmware). Marine forked at A.14 (86 PASS · 22 WARN · 0 FAIL) |
| Review 14 | A.13 | 16 (F143–F158) | three independent reviews of the A.12 push (24 + 8 + 7 findings) — all right: **the A.12 pin freeze had H5 (V15, 1.5 V) on the 5 V reference and J7 (the V25 regulator output) grounded**; the map is re-derived against NXP's own GEN3 net report (every supply ball and 164/165 ports agree; the four signals without a netlist cross-check moved to confirmed balls; the symbol now numbers pins by ball). **Firmware:** the DESAT ISR bypassed the 22–53 µs hardware delay (hold added for every caller), the ms clock wrapped wrongly after 71.6 min, keep_hv ignored the all-speed rule (b), placeholder fault routing and a readback posing as a lock — now an arming-evidence record keeps the gates inhibited until route, lock and validation records exist (fail closed); torque feasibility witness; stuck-on discharge detection. **Analog:** excitation monitor 18 k + C_AAF (3 mA unpowered), exciter TVS + PTC per line, motor-temp SMAJ5.0A + bound fuse, 47 Ω bias-LDO ballast for the production UCC12051-Q1 (80 mA). UCC14141-Q1 VDE certificate archived. Marine forked at A.13 (86 PASS · 22 WARN · 0 FAIL). Wording: 500–850 V, the 4XX AC-power envelope, safety work is engineering |
| Review 13 | A.12 | 8 (F135–F142) | rechecks of A.11: **the energy rule now applies at every speed**; resolver input bound with the MCU unpowered (12 k) and the SDADC's 220 pF C_AAF restored; verifier counts distinct assemblies; the fitted TPS55340-Q1 is 40 V abs (the 34 V "upgrade" premise was false); LDO thermal on the datasheet pad. **Production closure:** MCU ball map bound (the fabrication blocker, with seven port errors of the old list fixed), FS26 pins verified, reinforced optos (VOW3120) and biases (UCC14141-Q1) in place of the uncertified TLP152/QA01C-18, 40-way connector, 4XX can, Y-caps and discharge resistors bound to orderable MPNs; Marine forked at A.12 (86 PASS · 22 WARN · 0 FAIL); firmware delivered in `firmware/`; +₹1,269 |
| Review 12 | A.11 | 12 (F123–F134) | two whole-system reviews (28 + 35 findings): **SPO release rule missed the stored winding energy** (rule (a) now an energy inequality); **resolver exciter drawn with its MFB feedback swapped** (0.18 → 1.85 at 10 kHz); **the V_DC bias "MGJ2D150505SC" never existed** (UCC12050 per channel, V_IOWM 1697 VDC); Hall pull-downs drawn and the LEM drawn by terminal; resolver-pin short to KL30 limited to the MCU's 3 mA; **the LV-entry TVS as described conducted at a 24 V jump start** (24 V-stand-off -VR class bound, load-dump source resistance gated); ALM2402 package, NTC symbol, verifier guard, contract wording; −₹165/unit |
| Review 11 | A.10 | 0 (closure) | schematic-only rechecks of A.10 closed A9-S01, S9-01 and S9-02 and asked for no circuit change; leftover "13.4–18.1 V" wording corrected; ESR03 terminal-temperature limits added to the layout rules |

Three review claims were **rebutted with evidence** (900 V divider corner — system max is
850 V on a 0.1 % bottom leg; the GEN3-exact resolver monitor asymmetry; the discharge math —
it matches), and two review narratives were corrected in our own records at the reviewer's
insistence (CBOOT_PRE 100 nF was legal; VCC1 loss is a single-point failure whose outcome is
three-phase-open with ASC still commandable).

Full findings log + margin tables: [`docs/verification-report.md`](docs/verification-report.md).

| Metric | Power | Cap bank | Discharge | Card | Total |
|---|---|---|---|---|---|
| Components | 295 | 26 | 26 | 255 | **602** |
| Functional sections | 24 | 2 | 3 | 26 | 55 |
| Net labels / pin stubs | 813 | 42 | 59 | 803 | 1,717 |
| Sheet size | 44.6″ × 28.6″ | 8.1″ × 5.8″ | 11.1″ × 7.8″ | 44.6″ × 25.3″ | 4 sheets |

---

## 🔁 One platform, four SKUs — SiC or IGBT, 8XX or 4XX, same boards

The cap bank and discharge were already bolt-on assemblies, and the hiitio SiC (HCS600) and
IGBT (HCG600) modules share the D3 outline and 11-pin map — so **one power PCB, one control
card, one discharge PCB and one busbar drawing build every SKU**. A SKU is a module, a film-
can choice, a few values on existing pads, an identity resistor and a firmware parameter set.

| | 8XX SiC | 8XX IGBT | 4XX IGBT |
|---|---|---|---|
| Bus / f_sw | 500–850 V · 8–10 kHz | 500–850 V · 5 kHz | 250–500 V · 5 kHz |
| Peak / continuous | 220 / 120 kW (from 654 V) | 220 / 120 kW (from 654 V) | 150 / 90 kW (from 379 V) |
| Tj end of 30 s peak (S4; static-plate bound 135 / 142 / 133 °C) | 125 °C / 175 °C | 132 °C / 150 °C | 125 °C / 150 °C |
| Deltas vs SiC | — | module, DESAT 4.7 k/82 pF, gate 1.0/1.0 Ω, RT 8.2 k | as IGBT + 16 × 50 µF/600 V cans, discharge 220 Ω / 15 k |
| BOM @1k | ₹72,983 | ₹47,483 | ₹45,883 |

Recommendation (business case in [`docs/variants.md`](docs/variants.md)): lead with 8XX (same
hardware, best ₹/kW), make IGBT the volume SKU at both voltages, keep SiC as the premium 8XX,
bring up EVT-1 on the IGBT build. 220 kW at 400 V needs ≈560 A rms — a same-pin-map 900 A
module plus larger sensors and cap bank, not a new board. Generate: `npm run bom:all`.

---

## 🧪 Simulation — the drawn circuits at their operating points

`calculations/sim-verify.mjs` numerically simulates the released netlist's circuits in the
time and frequency domain on the shared loss model (`loss-model.mjs`). **23 PASS · 6 WARN ·
0 FAIL** — full table with per-row modeling assumptions: [`docs/simulation-report.md`](docs/simulation-report.md).

| # | Simulation | Key result (rev A.15) |
|---|---|---|
| S1 | Gate-power flyback: drain stress + **cycle-by-cycle start-up** | one burst to the rails in **73–240 ms** at KL30 9–14 V, every corner (FB now on its own aux rectifier — A6-R07); the A.5 values never started at 9 V |
| S2 | UB15 boost loop Bode (A.4.3 compensation) | f_c 1.9–2.5 kHz, **PM 72–75°** |
| S3 | DC-link ripple, center-aligned SVPWM, swept M/cosφ | worst **0.65·I**: 13.8 A/can at 340 A (15.4 A rating); 4XX 16.2 A/can (18 A) |
| S4 | 30 s thermal transient per SKU, from continuous steady state | **125 / 132 / 125 / 133 °C** (8XX SiC / 8XX IGBT / 4XX IGBT / 4XX SiC; IGBT and diode share the coldplate — RR07; junction and case taken static — R7-07; with no plate mass at all 135 / 142 / 133 / 143 °C, the 8XX IGBT a WARN until the thermal test — R8X-11) |
| S5 | Discharge ODE, bleeder counted once | **1.57 s nom / 1.81 s worst** (8XX), 1.70 s (4XX) |
| S6 | Current-loop phase margin per f_sw | ceilings **1.39 / 1.15 / 0.76 kHz** at 10 / 8 / 5 kHz |
| S7 | Gate peak current (DS §9.6) | SiC 3.1/2.5 A · IGBT 5.6/10 A vs the 10 A driver |
| S8 | SiC turn-off overshoot budget at 850 V/481 A (DS fall time) | 7.8 nH at 3.3 Ω cold → **13.6 nH at 6.8 Ω cold**, 22.9 nH hot — **DPT gate** |
| S9 | DESAT reaction, worst corners | SiC **3.1 µs** (tSC unpublished → vendor letter) · IGBT **4.8 µs at 400 mA / 10.1 µs at the 100 mA DS minimum** vs the 6 µs rating → release gate (RR04) |
| S10 | ASC hold-up through total LV loss | **0.5–3.1 ms** (was quoted 15 ms; round 7 starts the worst case at the 13.54 V low-corner rail) → sustained ASC requires KL30; motor rule in the contract |

| | |
|---|---|
| S1 | S2 |
| S4 | S5 |
| S8 | S10 |

<p align="center">SVPWM DC-link capacitor current simulation</p>

Hardware-only items are named per-row as bench gates (layout parasitics, core saturation,
SiC short-circuit withstand, EMI) — simulated claims and measured claims are never mixed.

---

## 🚀 Getting started

```bash
npm install
```

```bash
npm run build     # tscircuit netlists  → dist/boards/*/circuit.json
```

```bash
npm run sheets    # pages → footprint library → KiCad5 sheets → 100% pin-verify → KiCad 10 set → kicad-cli proof (footprints, pads per pin) → SVG → PDFs  (needs Chrome + KiCad 10.0.6+)
```

```bash
npm run bom       # docs/bom.md + per-board CSVs
```

### 📁 Repository map

| Path | What lives there |
|---|---|
| [`boards/power.tsx`](boards/power.tsx) · [`boards/capbank.tsx`](boards/capbank.tsx) · [`boards/discharge.tsx`](boards/discharge.tsx) · [`boards/control-card.tsx`](boards/control-card.tsx) | **Source of truth** — the four assembly netlists |
| [`packages/cells.tsx`](packages/cells.tsx) | Parameterized cells: gate-drive channel, flyback chain, iso V-sense, hall AFE, CAN, 40-way harness map |
| [`calculations/parts-db.mjs`](calculations/parts-db.mjs) | Designator→MPN/LCSC/price/alt database + on-sheet safety/discharge panel text |
| [`calculations/*.mjs`](calculations/) | The generator pipeline (pages · kicad5-gen · verify · kicad-sch-gen · kicad-sch-verify · print · pdf · bom) · `circuit-net.mjs` = the circuit.json netlist loader erc-audit and kicad-sch-verify share · `loss-model.mjs` = the one SKU table + loss model both verifiers use |
| [`boards/out-pdf/`](boards/out-pdf/) | 📄 Rendered PDF schematic set |
| [`kicad5/`](kicad5/) | `traction/` + `Traction-Inverter-SHIP.zip` = EasyEDA-Pro import variant · `traction-native/` + `Traction-Inverter-KiCad5-native.zip` = native KiCad 5 variant (round 15; both name every footprint in their F2 fields but ship no library — schematic and import sets, not the layout handoff) — both for KiCad 5–8 |
| [`kicad/`](kicad/) | `traction/` + `Traction-Inverter-KiCad-modern.zip` = the KiCad 10 `.kicad_sch` set (the schematics open in KiCad 9 too; the footprint library `traction.pretty` is the 10.0.6 format, so the footprint-enabled layout handoff is KiCad 10 — round 23): project, root with the four boards as sheet instances, every symbol embedded plus an identical project library; proved with `kicad-cli` (KiCad 10 resolves no symbol of the legacy sets) |
| [`docs/design-basis.md`](docs/design-basis.md) | Ratings, sizing math, safety concept, references |
| [`docs/dfm.md`](docs/dfm.md) | Manufacturability plan + sourcing tiers |
| [`docs/bom.md`](docs/bom.md) · [`bom-igbt.md`](docs/bom-igbt.md) · [`bom-igbt4.md`](docs/bom-igbt4.md) · [`bom-sic4.md`](docs/bom-sic4.md) | Generated BOMs, all four SKUs, with subsystem Pareto |
| [`docs/variants.md`](docs/variants.md) | The platform: four SKUs on one set of boards, economics, recommended launch path |
| [`firmware/`](firmware/README.md) | **Production firmware (rev A.23)** against the contract — round 24: a three-state acquisition-freshness contract for every slow ADC input (a stopped channel had stayed valid forever), the inductance map's flux-slope rule and the ripple limiter's exact piece bounds, the temperature-rate latch kept under an open/short sample, the V_DC channels' sticky expiry; round 23: the torque → current path solved jointly on the torque curve with a postcondition (FW-37) and the VESC gap closure — signed field update with anti-rollback over ISO-TP (FW-38), interlocked motor self-commissioning (FW-39), UDS diagnostics 0x19/0x22/0x2A/0x14 with 80 named DTCs (FW-40), fault-triggered waveform capture (FW-41), overspeed (FW-42), run-time statistics (FW-43), key-on offset adoption (FW-44) — plus the twelve defects the closed-loop simulator bridge found (F221–F232), and the extension: FW-45 saturation-dependent inductance tables and FW-46 cogging feed-forward (the maps are dyno measurements), the 64-bit divide out of every ISR path, the root of trust reported (DID 0xFD23), the UDS escape single frame accepted by every service; 444 tests / 5199 checks / 0 failed (host, −O2, ASan/UBSan, and the same suite on the Cortex-M7 under QEMU with the target compiler — `make qemu-test`), target-check 63 markers, TI_FW_ID 0x0A0F0016, CAL layout 4 (191 fields / 92 rows), 82 DTCs — safety state machine with fail-closed arming evidence, DESAT hold, monotonic clock, battery-path loss at any speed, fault manager, FS26 SBC, sensing (currents with stuck-channel detection, V_DC, resolver with cadence-locked frames; ADC map and schedule generated from the ball map), FOC, CAN-FD with E2E, discharge with stuck-on detection, NVM (CRC-32C slots, 64), four SKUs; the host simulation (`make test`, also ASan/UBSan and -O2) and the simulator bridge (`tool/bridge`, `make check`); traceability FW-01…FW-46 → tests; what still needs the target/HIL and the NXP RTD |
| [`docs/firmware-contract.md`](docs/firmware-contract.md) | Hardware → firmware contract: SKU identity, envelope, protection allocation, safe-state matrix, fault-latch recovery; §10d FW-34…FW-36 (round 18: sample freshness, resolver time base, latency sign) |
| [`docs/mcu-pin-manifest.md`](docs/mcu-pin-manifest.md) · [`calculations/mcu-ballmap.json`](calculations/mcu-ballmap.json) | **Pin freeze (rev A.12)**: every S32K396 ball, its function, our net; the seven port corrections found |
| [`docs/review-A15-disposition.md`](docs/review-A15-disposition.md) · [`.csv`](docs/review-A15-disposition.csv) | Review round 16 (three rechecks of A.14): exciter amplitude planes and gain, the unidirectional TVS, the conditional fault rows, the acquisition contracts |
| [`docs/review-A14-disposition.md`](docs/review-A14-disposition.md) · [`.csv`](docs/review-A14-disposition.csv) | Review round 15 (three rechecks of A.13): the exciter clamp topology, the native-KiCad variant, the PTC package, the ADC class, the low-speed contactor loss |
| [`docs/review-A13-disposition.md`](docs/review-A13-disposition.md) · [`.csv`](docs/review-A13-disposition.csv) | Review round 14 (three reviews of A.12): every finding classified, verified and dispositioned; the MCU map cross-checked against NXP's netlist |
| [`docs/review-A12-disposition.md`](docs/review-A12-disposition.md) · [`.csv`](docs/review-A12-disposition.csv) | Review round 13 (rechecks of A.11) and the production-closure register: MCU ball map, VOW3120 / UCC14141-Q1, connector, can, Y-caps, SQP10, Marine A.12, firmware |
| [`docs/review-A11-disposition.md`](docs/review-A11-disposition.md) · [`.csv`](docs/review-A11-disposition.csv) | Review round 12 (two whole-system reviews, 63 findings): every finding classified, verified and dispositioned |
| [`docs/review-A10-disposition.md`](docs/review-A10-disposition.md) · [`.csv`](docs/review-A10-disposition.csv) | Review round 10 (schematic rechecks of A.9) and its round-11 closure: every finding classified, verified and dispositioned |
| [`docs/review-A9-disposition.md`](docs/review-A9-disposition.md) · [`.csv`](docs/review-A9-disposition.csv) | Review round 9: every finding classified, verified and dispositioned |
| [`docs/review-A8-disposition.md`](docs/review-A8-disposition.md) · [`.csv`](docs/review-A8-disposition.csv) | Review round 8 and its cross-check: every finding classified, verified and dispositioned |
| [`docs/review-A7-disposition.md`](docs/review-A7-disposition.md) | Review round 7: every finding classified, verified and dispositioned |
| [`docs/review-A6-disposition.md`](docs/review-A6-disposition.md) | Review round 6: every finding classified, verified and dispositioned |
| [`docs/simulation-report.md`](docs/simulation-report.md) | Operating-point simulations (S1–S10) with waveform/Bode plots |
| [`docs/cost-rollup.md`](docs/cost-rollup.md) | Full unit cost + NRE + pricing guidance |
| [`docs/verification-report.md`](docs/verification-report.md) | **End-to-end verification**: findings log F1–F134, per-SKU margin tables, worst-case corners |
| [`docs/datasheets/`](docs/datasheets/) | Component datasheet pack (108 PDFs) + extracted parameters |
| [`docs/vendor-requests.md`](docs/vendor-requests.md) | **Vendor requests register** VR-01…VR-35 (round 23): every open vendor input as an exact question with the design condition, the acceptance criterion and the verifier row or gate it closes — HIITIO, NOVOSENSE, TDK, Faratronic, Murata, Bourns, Littelfuse, Diodes, Samtec, NXP, LEM, coldplate |
| [`docs/interface-requirements.md`](docs/interface-requirements.md) | **Vehicle / motor / harness interface requirements** IR-01…IR-42 (round 18): what the inverter assumes about the LV supply, the motor and resolver (data for the safe-state decision, Z_primary ≥ 60 Ω), the harness (exciter fault double event), the HV side, the coolant, the EOL steps and the single-vs-double-fault safety assumptions |
| [`docs/qualification-plan.md`](docs/qualification-plan.md) | **Qualification plan** (round 17): 92 executable procedures with fixtures, steps and numeric pass criteria for every gate, every WARN row, the simulation WARNs, the firmware silicon/HIL items and the EOL line (QP-PS/GD/SC/TH/LV/HV/RX/DS/SF/FW/FAI/EOL/MA) |
| [`docs/layout-handoff.md`](docs/layout-handoff.md) | **Layout handoff** (round 22): the layout engineer's entry point — the KiCad project with every symbol bound to a footprint in the shipped `traction.pretty` (standard patterns copied verbatim from KiCad 10, the module, isolators, transformer, connectors, can, fuse, choke, power resistor and crystal drawn from the archived datasheets — `traction.pretty/MANIFEST.md`), per-board project files, the layer/copper facts, the creepage basis (PD2/OVC II provisional), the placement and routing rules by block, the open decisions with their owners, and the first-article measurements the layout must keep possible |
| [`docs/firmware-vs-vesc.md`](docs/firmware-vs-vesc.md) | **Our firmware against the VESC firmware and VESC Tool** (round 23): a two-sided, evidence-cited feature and control matrix from the archived VESC sources (`docs/reference/vesc/`, GPL-3.0 reference copies — nothing linked or copied) — where VESC's breadth is real (sensorless observers, HFI, 12+ sensor drivers, self-commissioning wizards, a mature GUI), where ours is ahead (fail-closed arming evidence, hardware-only fast protection, the §6 safe-state framework, the postcondition-checked torque solve, E2E CAN, fail-closed calibration, traceability and the fault-injecting host simulation), and the ranked gap list that round 23 closes as FW-38 … FW-44 (signed firmware update with anti-rollback, interlocked motor self-commissioning, UDS fault-history/DTC export and telemetry, fault-triggered waveform capture, overspeed protection, run-time statistics, key-on offset refresh) |
| [`docs/tool-stack-decision.md`](docs/tool-stack-decision.md) · [`tool/`](tool/) | **Traction Tool** — the offline bench/service desktop application (round 23): Qt 6 / C++17 Widgets with Qwt plots (LGPL; no GPL chart modules) and Qt SerialBus for the CAN-FD adapters (`tool/qt/`), driving either a real inverter or the firmware's host simulation through the C bridge in `tool/bridge/` (`tool/PROTOCOL.md`); dashboard, live plots, controls with the firmware's own arming preconditions, the calibration parameter editor from `gen-params`, faults and alerts with a bug-report snapshot, analysis, terminal, firmware page. The decision record weighs Bun, Electron, Electrobun, Tauri and Qt honestly — the user chose Qt for maturity; after the extension: the signed update end to end over both transports, every commissioning routine including the inductance-map sweep and the ripple-map import, the CAN transport proved against the firmware over a virtual bus (`Tools ▸ Simulator on virtual CAN`), the root-of-trust banner, one UDS request at a time, the corresponding source and Qt's attributions shipped with the package (`scripts/licences.mjs`); 8 QtTest suites |

---

## 🗺 Roadmap

```mermaid
timeline
    title GEN-1 program
    section Done ✅
        Research : NXP GEN3 + Wolfspeed XM3 + TI TIDM-02014 read line-by-line : HIITIO catalog swept
        Rev A.1–A.3 : Schematic-complete set : DFM pass : verification campaign (F1–F36)
        Rev A.4–A.4.4 : Five external review rounds answered at the source (F37–F59) : real MPNs bound
        Rev A.5 : 4-assembly set · S1–S10 simulations · IGBT drop-in variant (HCG600, same pads) : F60–F62
        Rev A.6 : Review round 6 answered (46 findings) : F63–F76 · one platform, four SKUs (8XX/4XX × SiC/IGBT) : firmware contract
        Rev A.7 : Review round 7 answered (24 findings) : F77–F89 · ASC break-before-make in hardware · Schmitt-buffered safety logic · flyback lock-out fixed
        Rev A.8 : Review round 8 answered (12 findings + 23 cross-check items) : F90–F105 · a latched DESAT masks ASC on every path · every latch preset buffered · both optos inside 10–15 mA · FW-16 covers the FLT paths
        Rev A.9 : Review round 9 answered (6 findings + 2 gates + 15 cross-check items) : F106–F119 · QA01C-18 bound to its own sheet · FLT/RDY pull-ups on V5GD · FW-16 energy limit · no parking drain
        Rev A.10 : Schematic rechecks of A.9 answered : F120–F122 · RDY Schmitt-buffered · RASCG 0.33 W
        Rev A.11 : System review round 12 answered (63 findings) : F123–F134 · SPO energy rule · resolver MFB · UCC12050 bias · Hall pull-downs
        Rev A.12 : Rechecks + production closure : F135–F142 · MCU ball map bound · VOW3120 / UCC14141-Q1 barrier parts · connector, can, Y-caps, SQP10 bound · firmware/
        Rev A.13 : Round 14 (three reviews) : F143–F158 · H5/J7 fixed, map vs NXP netlist, ball pin numbers · firmware fail-closed arming, DESAT hold, clock, keep_hv · exciter/monitor/motor-temp protection · LDO ballast
        Rev A.14 : Round 15 (three rechecks) : F159–F164 · exciter TVS behind the PTC + 2.2 R · native-KiCad variant + matrix-aware verify · PTC 1812 · ADC class triple · contactor loss at any speed
        Rev A.15 : Round 16 (three rechecks) : F167–F173 · exciter gain 28 k + amplitude planes · unidirectional TVS · back-drive/TVS rows conditional · acquisition contracts (phase ADC, resolver age, coherent frames)
    section Next 🔜
        Pin freeze : DONE in A.12 — S32K396 289 balls bound from SPF-91122 + DS anchors : FS26 pins verified : connector bound
        RFQ : hiitio Ls + SiC SC letter + module quotes : Faratronic 4XX can : NOVOSENSE soft-off vs EN
        Layout : power-board floorplan around 3 modules : laminated busbar : card 6-layer
        Proto : EVT-1 on the IGBT build : SiC double-pulse at 850 V sets RG_OFF : SC tests : discharge timing : resolver loop
    section Then 🎯
        DVT : CISPR 25 EMC : ISO 16750 environmental : thermal endurance
        Production : casting tooling : EOL rig : 1k ramp @ ~₹1.15L (SiC) / ~₹0.90L (IGBT) per unit · 4XX IGBT ~₹0.92L
```

> [!NOTE]
> **⚠️ VERIFY-before-layout list (rev A.13)** — ① ~~S32K396 package and ball map~~ **closed in A.13** — the A.12
> freeze had two supply balls wrong (H5 = V15, J7 = V25; round 14); the map is now cross-checked ball by ball
> against NXP's GEN3 net report and every signal sits on a netlist-confirmed ball, the KiCad symbol numbers pins
> by ball ([`docs/mcu-pin-manifest.md`](docs/mcu-pin-manifest.md)); FS26 48 pins verified, connector bound · ② **SiC double-
> pulse at 850 V/481 A, cold and hot** sets RG_OFF (3.3–10 Ω; module Ls unpublished) ·
> ③ **short-circuit**: hiitio SiC letter, contained SC tests per silicon, NOVOSENSE statement on
> RST/EN during soft turn-off + I_STO spread · ④ coldplate Rth (0.045 K/W assumed) and can
> sharing · ⑤ bias bank at worst parts + VGT12EEM Isat/working insulation · ⑥ motor data for
> the safe-state matrix (and whether the HV backup bias is needed) · ⑦ FS26 OTP readback ·
> ⑧ ~~4XX can MPN~~ **bound in A.12** (Faratronic C3D1U506KFAA382; ripple rating checked at PO) · ⑨ LEM lead time — **order T2 parts at kickoff** · ⑩ LEM sign-off
> on the phase-busbar insulating sleeve (HC5FW/SP1 is the reduced-insulation variant, N7) · ⑪ ~~TLP152
> barrier rating~~ **closed in A.12**: both optos are Vishay VOW3120 (V_IORM 1414 Vpk, DIN EN 60747-5-5, CPG ≥ 10 mm; N8) ·
> ⑫ HIL then dyno: contactor opening under full regen. The FW-06 chain is ≤ 15.6 µs to the ASC
> request plus ≤ 7.6 µs ASC entry, a link peak of ≤ 906 V on 8XX (N9, RR06; UCC14141-Q1 low end, A.12).
> ⑬ LV-only gate-supply bench: six-domain VCC2 inside 13.5–17.0 V, from 9 to 16 V KL30 and at a
> 24 V jump start (A6-R06/R07).
> ⑭ ASC entry measured on all six V_GS, on every entry path (RR05).
> ⑮ Discharge-resistor fault-opening qualification (A6-R11).
> ⑯ ~~Confirm PTC25/PTC26 reach an eFlexPWM FAULT input~~ **closed in A.12**: R14/PTC25 = PWM_1_FAULT[2],
> P15/PTC26 = PWM_1_FAULT[0] — the same eFlexPWM_1 instance as the six outputs; every VDD_HV_A/B ball on V5A
> (`docs/mcu-pin-manifest.md`).
> ⑰ NOVOSENSE statement on DESAT during ASC with EN low (§8.12 marks it irrelevant); this
> decides the FS1B-ASC residual.
> ⑱ VOW3120 100 °C ambient vs the power-board interior; LED drive and timing at corners on both optos.
> ⑲ No-HV driver fixture: DESAT injected during PWM-ASC; the faulted gate must stay off and the
> healthy ones must release (UASCG) until an authorised reset (R7-01).
> ㉔ ~~Barrier working-voltage statements for the parts that only quote a hipot~~ **closed at BOM level in A.12**:
> PSASC/PSQD are TI UCC14141-Q1 (reinforced, V_IORM 1414 Vpk / V_IOWM 1000 Vrms, IEC 60747-17) and the Y-caps
> Vishay VY1 (Y1, 1500 VDC); what remains is the PO-time check that TI's VDE/UL certificates, listed "planned"
> in SLUSF10B §7.6, have issued (round 12, R1-F12; design-basis §6a). ㉕ Resolver bench: 8 V pp at 10 kHz from the SWG amplitude register against the
> excitation monitor, and the harness short-to-KL30 injection measured at the SDADC pins (R2-F04/F13).
> ㉖ Discharge resistor (re-scoped round 17): the no-flame property is closed on paper by the bound part's
> sheet — TT/Welwyn SQP "will not burn or emit incandescent particles under any condition of applied temperature
> or overload" (the Yageo alternate lacks the statement and is constrained in the BOM; VR-28) — so the ⑮
> stuck-ON test now only characterises the fail-open time (QP), it is no longer a release gate. ㉗ LV entry (re-scoped round 17): the entry is LET-THROUGH — every clamp stays dark at the 35 V test-B plateau
> (TPSMC33A-VR/TPSMC18A-VR anti-series pair at the pin ahead of the reverse Schottky, TPSMC33CA-VR on the power
> board), every downstream part is shown rated for it (FS26 36 V extended operation, boost 38/40 V, LDOs, flyback
> drain), a 100 µF hybrid capacitor absorbs pulse 2a and a 5 A fuse replaces the undersized polyfuse — closed on paper
> at every source impedance (F189); what remains is measured: QP-LV-02/03/04 (jump start, test B at the OEM's Ri, the
> other ISO 16750-2/7637-2 pulses) and the FS26 "limited period" duration asked of NXP (VR-29). Test A (unsuppressed
> dump) is not supported — IR-03 (central suppression, Us* ≤ 36 V at the pin).
> ⑳ FAULT_OUT wire-fault injection with V5A up, sleeping and off, a 35 V pulse, and FS1B asserted into
> the short (A7-N04, P-01).
> ㉑ V5GD-off state with the pull-ups on V5GD (A8-01): FLT/RDY low → SPO, nothing back-powers the dead domain.
> ㉒ FW-16 on HIL: skip/stored-pass rule, the FS_GPIO1 steps, FLT injection with the pad rule
> (R8X-02/03/17); motor commissioning: ASC-entry current vs the DESAT minimum (R8X-13).
> ㉓ Bias and gate levels (A8-N01/N02): UCC14141-Q1 output at no load/start-up/ON, QDIS V_GS, ASC entry at the low end.
> ㉙ Parking drain with the card in LPOFF (N17) and the self-test energy fixture at ≤ 13 V (A8-N03) (renumbered from a second ㉔ in round 17).
> ㉘ Terminal-fault bench (round 14, F04/F18; widened rounds 15–16; re-scoped round 17; two release gates restored
> round 18): each resolver excitation line and each motor-temperature line to 24 V/60 s and 35 V/400 ms with
> VEXD/the MCU on, off and cranking, positive and (where the OEM allocates it) negative. Characterisation for the
> sheet-bounded single fault (fault current ≥ 8 A — the ISO 16750-2 direct short: TVS energy ≤ 1.7 J against the
> exciter TVS's 5.3 J rectangular-equivalent — SMDJ7.0A-HRA since round 19 (F203) — PTC current ≤ 40 A at the IR-16 harness minimum), the PTC hold (IR-13)
> and the 35 V double event (IR-16 ≥ 0.37 Ω at 35 V since round 19 — round 18's 0.29 Ω was the 8.5 V-class figure and gives 42.6 A
> cold against the PTC's 40 A, 37.9 A at 0.37 Ω; round 21 F208 / IR-33). RELEASE GATES since round 18 (F191–F194): (a) QP-RX-05 — the
> reverse rail current into ULDOEX with its input at 0 V, cranking and inhibited: the diversion diodes DEXP/DEXN
> now sit on the amplifier node so the charging loop passes RSX (≈ 3.9 A / 60 µs with the 7.0 V clamp, judged by I²t), and the NCV4276C's
> 40 V output rating covers the node voltage only (VR-33); (b) QP-RX-04 step 2b — a sustained short through
> 0–100 Ω external at 12.6/14.4/16/24 V with the ECU asleep, where below 8 A the PTC's trip time is a typical curve
> and the tripped PTC's trickle leaves 0.9–1.7 W in the TVS at 12.6–16 V, 1.5–3.8 W with the 8.5 V class of round 18 (dfm.md: TVS copper island with the PTC thermally coupled
> on it; IR-42; VR-17). RSX is an anti-surge 0.5 W part (the powered negative fault). Since round 19 (F199/F200) the
> ≥ 8 A clearing measurement (trip ≤ 20 ms, ∫v·i ≤ 5.3 J at 0 / 0.14 / 0.5 / 1.33 Ω, 16 / 24 / 26 V) is a release criterion too —
> the sheet bounds only the 8 A point — and the Marine kit runs the same sweep at the ship's voltages (QP-MA-11: its
> 12 V rail is the platform's worst case). Measured for the record:
> PTC clearing waveform (cold, hot, post-trip), PTC/TVS/Schottky currents, the reverse rail current into
> ULDOEX, TVS temperature, buffer unharmed, excitation amplitude at the WINDING (≥ 6.5 V pp; the monitor plane is
> before the PTC) against the selected resolver's measured impedance; energy-limited source first (procedure in
> docs/qualification-plan.md). **Target evidence for the arming record** (F01/F02/F06):
> PWM-fault injection on PTC26/PTC25 with the CPU halted, the ADC-watchdog → PWM-fault chain ≤ 15.6 µs,
> REG_PROT lock readback, WCET — the firmware refuses to arm without it.
> Full list with owners: [`docs/review-A9-disposition.md`](docs/review-A9-disposition.md).

---

## 📚 References

| Source | What GEN-1 took from it |
|---|---|
| **NXP EV-INVERTERGEN3** (SPF-91122 / EV-POWEREVBHD2) | Control architecture near-verbatim: FS26 rails & FS0B/FS1B paths, OR-gated flyback enables, resolver AFE chain, hall AFE, PWM/PWMALT lockout, interlock signature |
| **Wolfspeed CRD300DA12E-XM3** (PRD-06975 + discharge PCB) | Passive-bleeder discharge numbers, gate-drive practice (±15/−4 rails, soft-shutdown, 2 µs dead-time guidance), DC-link class |
| **TI TIDM-02014** (TIDUF23A) | Safety decomposition: PMIC SAFE-OUT OR-gate, LVSS strap matrix concept, dual-path ASC authority |
| **HIITIO catalog** (hiitio.com, 2025 datasheets) | HCS600FH120D3C1 (SiC) + HCG600FH120D3E1EA (IGBT variant, same D3 pads/pins), HCM75S12T4K3; EconoDUAL 3 footprint strategy |

---

<p align="center">
  
  <br/>
  <sub><b>Traction Inverter GEN-1</b> · rev A.15 · one platform, four SKUs (8XX/4XX × SiC/IGBT) · schematic-complete, layout next.<br/>
  Proprietary — © Vectivolt. Reference designs cited remain property of their respective owners.</sub>
</p>

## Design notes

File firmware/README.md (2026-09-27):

# Traction inverter firmware (S32K396 + FS26)

This is the application firmware for the 220 kW / 850 V traction inverter. It covers four SKUs:
8XX SiC, 8XX IGBT, 4XX IGBT and 4XX SiC. It implements `docs/firmware-contract.md` (rev A.18),
§8/§8a of `docs/design-basis.md`, the round-12 disposition, the ball map
`calculations/mcu-ballmap.json`, the round-14 review of commit cfd35a7 (see "Round 14"), the
round-15 rechecks of commit a8c75eb (see "Round 15"), the round-16 rechecks of commit 32214be (see
"Round 16"), the round-17 closure of every open item (see "Round 17": each one is now a decision in the
contract or a row of the target checklist `docs/target-bringup.md`), the round-18 rechecks of commit 4425af9
(see "Round 18") and the round-19 rechecks of commit e315bf1 (see "Round 19"). It is C11 with no dynamic memory
and no recursion, and every loop is bounded. It uses fixed-width types and single-precision float only.

The Wolfspeed CRD200 package was used only to check which structure is usual for such a
firmware. No code was taken from it.

## Build and test

```
make test          # host build of the firmware + simulation + tests, then run (cc, warnings = errors)
make target-check  # syntax-check src/platform/s32k396 on the host with the RTD calls compiled out, and check
                   # that every TODO(<kind>) marker has its row in docs/target-bringup.md (and back)
make target        # S32K396 build: needs S32K3_RTD=<path> and arm-none-eabi-gcc (see Makefile)
make params        # regenerate include/params_<sku>.h + cal_ranges.h (node tools/gen-params.mjs)
make board-map     # regenerate src/platform/s32k396/board_pins.h from the ball map (node)
make qemu-test     # the same suite built by arm-none-eabi-gcc for the Cortex-M7, run on QEMU (below)
make target-size   # text/data/bss of src/ + the s32k396 platform for the M7 (RTD calls compiled out)
make clean
```

`make test` compiles with `-std=c11 -Wall -Wextra -Werror -Wshadow -Wdouble-promotion
-Wmissing-prototypes -Wstrict-prototypes -Wundef -Wpointer-arith -Wcast-qual -Wvla`. Test files
alone get `-Wno-double-promotion`, because their reference arithmetic is done in double. Current
result (round 24: F241, the slow channels' acquisition freshness, the FW-45/FW-46 review and the F243/F244 follow-ups): **443 tests, 5195 checks, 0 failures**, also with `-fsanitize=address,undefined` and at
`-O2` (`make BUILD=build/asan test CFLAGS="-O1 -g -fsanitize=address,undefined"`,
`make BUILD=build/o2 test CFLAGS=-O2`).

For the target build you need these, which are not in this repository:

- The NXP S32K3 RTD for S32K39x, with the IP drivers FlexPwm_Ip, Adc_Sar_Ip, Bctu_Ip, Sdadc_Ip,
  Dma_Ip, Trgmux_Ip, Lcu_Ip, Siul2_Port_Ip, Siul2_Dio_Ip, Lpspi_Ip, FlexCAN_Ip, Stm_Ip, Swt_Ip,
  Fee/Fls (C40), Fccu_Ip, Clock_Ip and IntCtrl_Ip.
- The S32K39 device headers.
- An S32 Config Tools project that generates the configuration symbols named in the RTD markers
  (`docs/target-bringup.md` lists every one).
- A linker script with two sections: `.ti_retained` (no-init, survives an MCU reset) and
  `.ti_nocache` (for the eDMA buffers).

The SKU is picked at build time with `SKU=TI_SKU_8XX_IGBT` or similar. At boot, HW_ID and the
calibration record must agree with it (FW-01/02/20).

**Arming is blocked until everything below is provisioned — fail closed, nothing is assumed.**
1. `cal_fs26_prog_id` = the M_PROGID of the FS26 OTP variant that was procured (0xFFFF = unbound).
2. The calibration record sealed to the device UID (FW-20).
3. The arming evidence (`src/safety/arm_evidence.h`, round 14), all five items:
   - **ROUTE_BOUND**: `src/platform/s32k396/s32k396_board_cfg.h` filled from the S32K39 RM IMCR table
     (checklist T-01). Until then a target build stops with `#error`; filled values must be non-zero with
     two different IMCR indices (`_Static_assert`). The IMCRs are read back at run time.
   - **CONFIG_MATCHES**: the eFlexPWM fault lock-down image reads back.
   - **PROTECTION_LOCKED**: the REG_PROT soft-lock bits and the hard lock read back set
     (offsets in `s32k396_cfg.h`, checklist T-03). Never true by default; false in `target-check` builds.
   - **FAULT_ROUTE_VALIDATED** and **OVP_ROUTE_VALIDATED**: an EOL/HIL validation record in NVM
     (`NV_REC_VALIDATION`), CRC-sealed and bound to `TI_FW_ID`, the SKU and the device UID: the pad →
     PWM fault injection passed, and the FW-06 chain was measured within 15.6 µs (checklist T-05; this image
     is `TI_FW_ID` 0x0A0F0015, round 23 — the second round-23 image; 0x0A0F0014 was the torque-solver image).

   Anything missing is a DTC (`DTC_ARM_EVIDENCE` or `DTC_PWM_LOCK`), the state machine never leaves
   the inhibited state (no FS0B release, no FW-16 energisation, no `MCU_GATE_EN`), and INV_STATUS
   byte 15 names the missing items. The host default is "nothing validated": the test harness
   binds the route and stores a valid record the way the EOL/HIL rig would (`tests/harness.c`).

### QEMU (target ISA) run

`make qemu-test` (`qemu.mk`) builds exactly the `make test` file set — the firmware, the host simulation platform and
the tests, with the same warnings as errors — with arm-none-eabi-gcc for the S32K396's core (`-mcpu=cortex-m7
-mfpu=fpv5-sp-d16 -mfloat-abi=hard -mthumb -O2`, newlib), links it for QEMU's `mps2-an500` board (a Cortex-M7;
`qemu/startup.c`, `qemu/mps2-an500.ld`) and runs it there with semihosted output and files. It passes only on QEMU
exit 0 and "N tests, M checks, 0 failed". Result: **402 tests, 4707 checks, 0 failed** — the host's counts and output —
in 1089 s under TCG (about 125 times the host binary; QEMU 11.1.1, Arm GNU Toolchain 14.3.Rel1). It needs
`qemu-system-arm`, node (the capture decoder test runs it on the host through semihosting) and an arm-none-eabi-gcc
with newlib (`ARM_CC=…`: Homebrew's `arm-none-eabi-gcc` formula has none, the Arm GNU Toolchain has).

It proves the firmware logic on the target's instruction set, FPU and C ABI: Thumb-2 code from the target compiler,
single-precision hard float with doubles in soft-float (the S32K396's FPU is single precision, data sheet §3.2),
32-bit `long`, `size_t` and pointers, newlib's libm, the M7's alignment faults. And it is the run that executes the
target's rounding: the host build fuses `a*b + c` into one multiply-add (Apple clang's default contraction), GCC
under `-std=c11` does not (a host build with `-ffp-contract=off` prints what the M7 prints). It does not prove
peripherals (the host simulation platform runs, not `src/platform/s32k396`), the RTD, interrupts or preemption (the
simulation calls the ISRs in turn), timing (TCG is not cycle-accurate; the one host-timing check reads 0 here, see
`qemu.mk`), the memory map, caches, TCM, ECC or the lockstep core — `docs/target-bringup.md` T-59 says what it
pre-empts.

GCC for the M7 found test-code defects that clang on arm64 does not flag; fixed, no assertion changed: `%u` for
`uint32_t` (an `unsigned long` on arm-none-eabi) in four failure messages, two CAN frames read after `last_status()`
may have left them unwritten, a 256-byte buffer for a command of up to 300, a sign-compare (`tests/test_scenarios.c`,
`tests/test_capture.c`).

`make target-size`: src/ with the s32k396 platform (RTD calls compiled out) for the same core — text 83 921, data 33
(32 of them `.ti_retained`), bss 127 747 bytes at -O2 (text 71 665 at the `make target` -Os). The libraries, the RTD,
the start-up and the stacks come on top. The S32K396 has 6 MB program flash and 800 KB RAM, 288 KB of it TCM
(`docs/datasheets/S32K39.pdf`, Table 1).

Last run on the final round-24 tree: **444 tests, 5199 checks, 0 failed** on the Cortex-M7 under QEMU (fpv5-sp-d16), 3 575 s wall (a Qt build ran concurrently; round 23's run took 1 412 s) — the host's exact counts, byte-identical output with `-ffp-contract=off`.

## Architecture

```
            app/app.c   integration: ISR bodies, 1 ms task, background; one g_app instance
   ┌──────────┬──────────┬───────────┬──────────┬─────────────┬─────────┐
 safety/    control/    sense/      comms/     discharge/    nvm/        pure logic: no HAL
 state      resolver    current     CAN E2E    QDIS FW-17/18 params      calls except where
 machine,   FOC, SVPWM  V_DC        UDS DTC,   precharge     calib FW-20 a driver needs one
 §6 matrix, MTPA/FW     temps       UDS 0x27/  FW-19, τ      NVM log     (fs26, bridge,
 fault mgr, gains,      HVIL, IGN   0x31 FW-32               queue       gate power/self-test)
 FS26, bridge, dclink   HW_ID, VSUP FW-11
 gate power/self-test
   └──────────┴──────────┴───────────┴──────────┴─────────────┴─────────┘
            hal/*.h     10 interfaces: pwm adc sdadc swg gpio spi_fs26 can nvm timer wdog
                        + sdadc_ring.c: the resolver frame protocol both platforms run (round 16)
   ┌──────────────────────────────┬──────────────────────────────────────┐
 platform/s32k396                  platform/host
 ball-map tables (generated),      simulation of the card: DRV_EN chain, fault latch +
 register images, RTD bodies       one-shot, ASC latch, drivers, FS26, ADC watchdog, the
 (RTD markers where the SDK binds) resolver excitation chain + per-channel eDMA, CAN, NVM with
                                   power loss; injection + time control
```

These rules shape the code:

- **Hardware first.** eFlexPWM_1 FAULT0 (FLT_HS_N) and FAULT2 (FLT_LS_N) force all six outputs
  low. FAULT1 is the ADC watchdog for FW-05 and FW-06 and forces the high sides only. All three
  are fail-safe with manual clear, locked at init and read back (`s32k396_pwm.c`,
  `s32k396_cfg.h`). The DRV_EN chain, the fault latch and the ASC latch act without code.
  Software only confirms, latches, logs and decides the §6 follow-up.
- **No torque without a fresh, valid command.** This needs an E2E CRC, an alive counter, age
  ≤ 20 ms, and finite values (NaN/Inf are rejected at the CAN decoder, in the torque path, in
  FOC and at the PWM write).
- **Every sensor value has a validity flag and a sample time** (`ti_meas_t`, per-channel stale
  timers). Round 16: a phase-current triplet counts only when all three channels of one trigger arrived,
  a resolver frame only when all three channels of one epoch did, and the resolver angle expires
  `cal_rslv_hold_us` after its newest frame whether or not a new one arrives. Round 18: freshness is judged at
  a time read after the sample was read, with a signed age (`ti_stale`), and a resolver frame is stamped with
  its block start on the SDADC cadence, whatever its interrupt's latency. Round 19: that cadence is dated by the
  SWG start, never by a completion, and a ring whose DMA lost the carrier phase is restarted, not re-guessed.
- **One parameter set per SKU.** `include/params_<sku>.h` is generated from the contract tables
  and has 191 fields (round 24). 92 of them are `cal_*` values the contract does not fix, mostly hardware
  timings and tolerances. Each has its contract default and a `[min, max]` range
  (`include/cal_ranges.h`), checked at boot.
- **Units:** see `include/ti_types.h`. Time is `uint32_t` µs or ms, compared only through
  `ti_elapsed()`/`ti_age()` — and a sensor stamp's freshness through `ti_stale()` (round 18: signed, the stamp
  may postdate the check). One time domain (round 14, A12-R06, `src/hal/timer.h`): µs intervals use
  the raw counter `hal_time_us()`; every ms stamp comes from `hal_time_ms()` = (uint32)(us64 / 1000),
  where us64 is the counter extended to 64 bits (read at least once per 71.6 min wrap: the 1 ms task
  does), so ms wrap at 2^32 like any uint32. Never `hal_time_us() / 1000`. ADC values are 12-bit
  codes. Speed is mechanical rpm. Angles are electrical rad in [0, 2π).
- **Safe states.** `safety/safe_state.c` is the §6 matrix as a pure function. It has speed
  columns (n < n_x, n ≥ n_x, unknown ⇒ high), the rule (a) winding-energy screen and the rule (b)
  release. `safety/fault_mgr.c` combines rows (forced SPO wins, otherwise the highest rank) and
  owns the FW-15 retained record and the one authorised retry.
- **Timing:** see `docs/timing.md`. The current loop runs at 2·f_sw on the BCTU trigger, the
  1 ms task handles supervision, and the fault ISR is the highest priority.

## Modules (lines, `wc -l`)

| Directory | Lines | Contents |
|---|---|---|
| `include/` | 1180 | types/units (+ `ti_stale`), parameter struct, 4 generated SKU sets, CAL ranges |
| `src/util/` | 104 | math helpers, CRC-8 (0x1D, SAE J1850) and CRC-32 |
| `src/hal/` | 632 | the 10 HAL interfaces (timer: the 64-bit time base), the shared resolver frame protocol (round 16; round 18: the cadence stamp, the servicing deadlines, re-acquisition; round 19: the SWG-start origin, the re-sync from the clock, `lost` and the producer restart) |
| `src/sense/` | 680 | current (FW-05, stuck-channel check, lost triplets), V_DC (FW-07/18), temperatures (FW-13), HVIL (FW-09), HW_ID (FW-01/02), IGN, the LV supply (FW-33) |
| `src/control/` | 931 | resolver (FW-10: bounded hold, amplitude planes, SWG ramp, the latency's sign), FOC/SVPWM, MTPA/field weakening/limits and the voltage witness (FW-03/04), gains, the DC-link trim (FW-08: a regen limiter in RUN) |
| `src/safety/` | 2134 | state machine, §6 matrix, fault manager (FW-15), FS26 (FW-12, + its AMUX for FW-33), bridge sequences + DESAT hold and the ASC-exit release wait (round 18: the FW-15 low wait on the bridge's own clock), gate power (FW-14), self-test (FW-16), arming evidence |
| `src/comms/` | 687 | CAN command/status with E2E (FW-11), UDS DTC store, UDS SecurityAccess + the service-lock routine (FW-32) |
| `src/discharge/` | 279 | FW-17/18/19, FW-02 τ, unexpected discharge |
| `src/nvm/` | 520 | parameter sets (+ the exciter plane checks), calibration (FW-20), NVM log and queue (validation and service records) |
| `src/app/` | 1229 | integration (+ the current-loop liveness check FW-31, the diagnostic bus, the check times of FW-34, the resolver producer restart of FW-35) |
| `src/platform/s32k396/` | 1961 | generated ball-map tables, the ADC map and its derived schedule, register images, REG_PROT layout, the board configuration the RM fills, drivers with RTD bodies (three SDADC DMA interrupts) |
| `src/platform/host/` | 2044 | simulation of the card, FS26 (its oscillator tolerance and AMUX) and MCU peripherals (REG_PROT, route binding, MCU reset, per-channel eDMA, the excitation chain; round 18: ADC reads that take time, per-channel interrupt hold-off, the overrun flag, a preempting ISR; round 19: the DMA blocks triggered by the SWG start, its start latency) |
| `tests/` | 7893 | 31 suites (one file per module + time + sdadc + uds + scenarios), 290 tests, harness (two exact clocks, ADC-level noise) |
| `tools/` | 368 | parameter and board-map generators |

## What is verified where

**Host-verified** (`make test`, against `src/platform/host`):

- all decision logic: §6 rows and the energy rule on the screening motor, the fault manager,
  the state machine and §9 order, the FW-15 sequence including the one-shot/latch/ASC-latch
  model, FW-16 steps a–h with each chain term stuck permissive, the FS26 protocol (CRC, Q&A
  answer, release word from the datasheet example, error counter), CAN E2E, discharge and
  precharge plausibility, NVM A/B with torn writes, calibration and parameter validation;
- control: the current loop closed on an RL model of the screening motor, anti-windup, MTPA,
  field weakening, the resolver on synthesised SDADC blocks (−24° compensation, acquisition at
  speed, wrap, missed blocks);
- timing **as modelled**: the FW-06 chain with its allocated delays, the dead time before
  PWM-ASC, the first HS pulse after ASC_CLR (`cal_asc_release_ns` + the dead time from its falling edge), and
  FW-15's ≥ 1.5 ms low;
- the S32K396 register images: the fault lock-down value, PWM counts and edges, mode images,
  ADC indices and thresholds (`tests/test_platform_cfg.c`), plus the ball-map binding;
- round 14: the DESAT hold on every EN-drop path (ISR, §6 decision, FW-15, FW-16), the time base
  across the 32-bit µs wrap (freshness, dwell timers, DTC stamps, the 1 s retry), keep-HV and
  "no safe state proven" at every speed, the host REG_PROT model (CPU and DMA writes rejected, a
  watchdog reset re-locks), the arming-evidence refusals, the torque→current voltage witness on a
  motor-map sweep, the stuck-channel check, and the stuck-on QDIS service lock;
- round 15: every ADC input's instance/subtype/channel against the ball map and the conversion schedule
  derived from it (the chain of every slow input, ADC1's injected chain, the V_DC ch2 gap), HW_ID read
  from a started conversion, and a battery-path loss while armed at zero/low/high/unknown speed ×
  OPEN/INVALID/stale report (row, same-invocation outputs, targets, PWM/ASC, CAN status);
- round 16: the resolver angle's expiry at the hold (standstill, low speed across the µs wrap, 10 000 rpm)
  with the §6 response and a controlled re-acquisition, empty reads at 10/20 kHz that never fault; the frame
  protocol on a per-channel eDMA model (a frozen or late channel, a completion between channel copies, a
  preempted reader, interrupts held off, the epoch wrap); every combination of missing phase channels, a
  stopped current loop; the exciter planes (three SWG corners, a 25 Ω resolver, a tripped PTC);
- round 17: zero current (id = iq = 0) under the battery-lost row at 1000 rpm and in field weakening at
  7000 rpm, reported as 0 Nm, with the DC-link trim never engaged; the trim as a regen limiter in RUN with the
  battery present (idle in range, taking regen back above it, handing it back); the UDS service routine
  refused without a key, with HV present, with the bridge armed, and accepted with a (test) key — the clear
  taking effect at the next power-up; the SecurityAccess protocol (seed/key, one key per seed, the attempt
  lockout, malformed requests); the FS26 answered every 2 ms on the target's exact tick grid at its oscillator's
  −5 / 0 / +5 %; the first high-side pulse after an ASC exit behind the release deadline (SiC and IGBT); KL30
  at 35 V for 400 ms and a 24 V (and 26.5 V) jump start for 60 s as information, a longer overvoltage taking
  the orderly ramp and recovering;
- round 18: every ADC read taking 1, 5 or 50 µs before it stamps (the target's order), also straddling the 32-bit
  µs wrap, and the current-loop ISR preempting the 1 ms task — currents, V_DC and the resolver stay fresh; a DESAT
  that preempts the task keeps FW-15's ≥ 1.5 ms low (also across the wrap); SDADC
  completion interrupts held off within the deadline (stamps exact), past it (rejected, re-acquired), for exactly
  a lap (never fresh), one channel lapping, all three stalled, a late anchor, both wraps, lost samples; the
  resolver latency against an independent rotor at ± 3000 / 10 000 rpm and 25 / 50 µs;
- round 19: the resolver cadence dated by the SWG start — first completions 0–800 µs late (accepted within the deadline
  + the 3 µs uncertainty with exact stamps, rejected beyond), a SWG start latency of 1–3 µs inside the declared
  uncertainty, a constant 40 / 60 µs delay never published, a delay rejected once never absorbed after the break (also
  as the FOC angle at 10 000 rpm), a channel paused one period, a DMA stall and 2^32 µs of silence against the clock,
  an early completion, an interrupt late inside the origin's uncertainty (no false loss), the restart limit per key
  cycle across an MCU reset;
- round 24 (F241): every slow-list input stopped (its code and stamp frozen while the input moves on) or never
  converted, each alone while the current loop and V_DC run: the seven temperatures, V5GD and VOFS, KL15, INTRLOK_N,
  VSUP and HW_ID — held for `cal_temp_hold_ms`, then withdrawn with their consumers' responses; a constant input
  converted on schedule valid for three minutes; the hold across the 32-bit µs wrap; F243: a latched rate fault through
  an open or short sample (the channel stays RATE and invalid, the derating stays, `DTC_TEMP_OPEN_SHORT`); F244: a stopped
  V_DC converter stale until a new conversion, also at every µs within 150 µs of 2^32 µs of its stamp's age.

**Needs the target, HIL, EOL or the bench:** everything is in **[`docs/target-bringup.md`](docs/target-bringup.md)**
— one row per open marker in the sources (RTD, RM, HW-RM, HW, EOL, REL), with the acceptance check and what
holds the image closed until then, plus the WCET of `docs/timing.md`, the commissioning values (`cal_*`) and
the vehicle-integration items. `make target-check` keeps the markers and the rows in step.

## FW-xx mapping

The full matrix, down to function and test name, is in [`docs/traceability.md`](docs/traceability.md).
It also maps every edge case from the task to its test.

| FW | Code | Tests | Host | Target item (`docs/target-bringup.md`) |
|---|---|---|---|---|
| 01, 02 | sense/hwid.c, app.c (slow list before HW_ID), discharge.c (τ) | hwid, discharge, scenarios | yes | T-14 (HW_ID on real cards), T-37 (τ per bank) |
| 03, 04 | control/torque.c (+ voltage witness), sense/temp.c | torque, state_machine, scenarios | yes | T-37 (dyno, thermal, `cal_peak_recovery_s`, `cal_vdyn_reserve_frac`) |
| 05 | sense/current.c (+ stuck channel, lost triplets), app.c, s32k396_adc/pwm.c | current, params, platform_cfg, scenarios | logic + modelled compare | T-08…T-10 (ADC WD → FAULT1), T-12 (BCTU list) |
| 06, 06a | sense/vdc.c, app.c, safety/bridge.c (the ASC-exit release wait) | vdc, bridge, scenarios | yes, modelled timing | T-05 (15.6 µs on HIL), T-08, T-11, T-36 (the exit edge) |
| 07 | sense/vdc.c | vdc, scenarios | yes | T-07 (EOL gains) |
| 08, 08b | control/dclink.c (the RUN-only regen trim), safe_state.c, fault_mgr.c, can_cmd.c, app.c (battery path at every speed; zero current under the row), state_machine.c | dclink, safe_state, fault_mgr, state_machine, scenarios | yes | T-37 (trim gains on the real bank), T-38 (rule (b), BMS) |
| 09 | sense/hvil.c | hvil, scenarios | yes | T-38 (harness signatures) |
| 10 | control/resolver.c, hal/sdadc_ring.c, s32k396_resolver.c, app.c | resolver, sdadc, params, calib, scenarios | yes | T-28…T-31 (SDADC/SWG/eDMA), T-07 (EOL planes), T-37 (latency), T-40 (completion latency) |
| 11 | comms/can_cmd.c, torque.c | can_cmd, torque, scenarios | yes | T-38 (vehicle DBC) |
| 12 | safety/fs26.c (+ the answer cadence), app.c (the answer first in the task) | fs26, scenarios | yes (model of the FS26, its oscillator tolerance) | T-32…T-34 (silicon: answer, spacing, MCU reset; OTP) |
| 13 | sense/temp.c | temp | yes | T-38 (sensor parts) |
| 14 | safety/gate_power.c | gate_power | yes | T-37 (RDY timings) |
| 15 | app.c, fault_mgr.c, bridge.c (+ DESAT hold), arm_evidence.c, s32k396_pwm.c | fault_mgr, bridge, safe_state, gate_selftest, calib, scenarios, platform_cfg | yes | T-01…T-05, T-15 |
| 16 | safety/gate_selftest.c | gate_selftest, state_machine | yes | T-16, T-17, T-37 (chain timings) |
| 17, 18, 19 | discharge/discharge.c, app.c (service lock) | discharge, state_machine, scenarios | yes | T-37 |
| 20 | nvm/calib.c, nvm/nvlog.c | calib, nvlog, scenarios | yes | T-07, T-25 (Fee), T-27 (UID) |
| 21 | implemented as FW-38 (round 23, contract §10f): boot/verify.c, update.c, uds_update.c, boot.c; app.c (`update_conditions`, `update_enter`) — see "FW-38" below | update, uds_diag | yes (the check, the update state, the bootloader decision under power cuts) | T-44…T-50 (flash driver, key, reset, bootloader binary, HSE) |
| 31 | app.c (`app_task_1ms`: current-loop liveness) | scenarios | yes | T-22 (ISR rate) |
| 32 | comms/uds.c, app.c (`service_clear`, `diag`) | uds, scenarios | yes | T-26 (diagnostic RX), T-35 (the key) |
| 33 | sense/vsup.c, safety/fs26.c (the AMUX), app.c (`sense_slow`, `detect`) | scenarios | yes (the FS26 AMUX modelled) | T-39 (the reading, the profiles on the bench), T-37 (the bands) |
| 34 | ti_types.h (`ti_stale`), app.c (`sense_fast`, `app_task_1ms`, `recovery`), current.c, vdc.c, resolver.c (`rslv_age`), bridge.c (`br_rec_step`) | time, current, vdc, resolver, bridge, scenarios | yes (the target's read-then-stamp order modelled) | T-36 |
| 35 | hal/sdadc_ring.c, s32k396_resolver.c (`hal_swg_start`: the origin; `hal_sdadc_restart`), app.c (the restart, the DTC) | sdadc, params, scenarios | yes (per-channel eDMA and interrupt model, triggered by the SWG) | T-40 (latency from the carrier boundary, cadence), T-41 (the flags wired to `lost`), T-42 (the SWG start latency), T-30, T-28 |
| 36 | control/resolver.c (`rslv_theta_e_at`) | resolver | yes | T-37 (the latency's sign on HIL) |

## Round 14 (three reviews of commit cfd35a7)

**Ball map rev A.13 (regenerated `board_pins.h`).** The A.12 map had H5 on the 5 V reference (it is V15, 1.5 V)
and J7 grounded (it is V25); the map was re-derived against NXP's GEN3 net report and four signals moved to
netlist-confirmed balls: HW_ID → B5 (PTE0, ADC3_P0), NTC_A → T15 (PTC11, ADC5_S11), MT2_SIG → D5 (PTE26,
ADC1_P0), ASC_REQ → U4 (PTD7, MSCR 103). `make board-map` after any ball-map change; `tests/test_board_map.c`
pins the safety GPIO MSCR indices.

Rule for every item: **fail closed** — when evidence is missing the gates stay inhibited. Each
change has regression tests that fail on the pre-fix source and pass now (the before/after run is
described in `docs/traceability.md`).

| ID | Defect | Change | Tests |
|---|---|---|---|
| A12-R05 | The fault ISR's FLT branch, and every SPO/FW-15/FW-16 path, lowered `MCU_GATE_EN` at once. It is an undelayed input of the DRV_EN AND gate, while the fault latch delays FLT → DRV_EN 22–53 µs so the NSI6611 finishes its soft turn-off (RST/EN during it is unspecified). | The PWM inhibit stays immediate. Once a FLT line is seen low, no software path lowers `MCU_GATE_EN` until `cal_desat_en_hold_us` (60 µs, range 55–250) after that first sight. The hold lives in `bridge.c`: every drop goes through `en_low()` (br_spo, br_rec_start, the FW-15 failure path, FW-16 through br_spo), which only records a pending drop; `br_service()` (current-loop ISR, 1 ms task) carries it out. The hold start is a fresh time read after the FLT lines were read. Without a FLT line low the drop is immediate. Arming and PWM-ASC entry are refused while a drop is pending. | bridge: `desat_hold_keeps_en_until_the_hold_then_drops_it`, `desat_hold_covers_br_rec_start_and_recovery_still_works`, `non_desat_spo_drops_en_at_once`; gate_selftest: `failed_test_with_a_desat_drops_en_only_after_the_hold`; scenarios: `desat_at_speed_holds_en_through_the_hold_then_reset_and_pwm_asc`, `desat_at_low_speed_spo_waits_for_the_hold`; params: `round14_cal_defaults_and_ranges` |
| A12-R06 | ms = `hal_time_us()/1000` jumped 4294967 → 0 at the 32-bit µs wrap: an 8 ms-old frame read 4 290 672 337 ms old (false VCU/BMS staleness), dwell timers expired, a DESAT retry could start ≈100 ms after the event. | One time domain (`hal/timer.h`): `hal_time_us64()` extends the counter (the same `ti_time64_extend` on both platforms, inside a critical section), `hal_time_ms()` = (uint32)(us64/1000). Every ms producer converted (app.c, nvlog.c; the 1 ms task derives µs and ms from one 64-bit read). DTC first-occurrence stamp no longer treats 0 as "unset". The simulation can start next to the wrap (`sim_reset_at_us`). | time: `us64_extension_survives_repeated_wraps`, `sim_clock_across_the_microsecond_wrap`, `can_freshness_across_the_microsecond_wrap`, `dtc_time_stamps_across_the_microsecond_wrap`; scenarios: `running_across_the_microsecond_wrap_keeps_fresh_frames_fresh`, `boot_across_the_microsecond_wrap_reaches_armed`, `desat_retry_waits_1s_across_the_microsecond_wrap`, `dtc_time_stamps_across_the_microsecond_wrap_in_the_application` |
| A12-R08 | `keep_hv` only after a DESAT at n ≥ n_x; a 0 rpm, 340 A rms SPO relying on rule (b) reported keep_hv = 0. | `keep_hv` = the action holds SPO, rule (a) fails and the battery is present, at any speed, for every row whose premise is not a lost battery; re-evaluated each update, so it holds until rule (a) is met for the present current/speed, and ASC clears it. Battery absent: keep_hv = 0 and "no safe state proven" (fault_mgr `no_safe_state`, INV_STATUS b14.0, live) plus DTC_SPO_ENERGY. | safe_state: `keep_hv_follows_the_battery_as_the_sink_at_every_speed` (48-case cross product); fault_mgr: `keep_hv_held_until_rule_a_and_no_safe_state_without_battery`; scenarios: `standstill_desat_at_rated_current_reports_keep_hv_on_can`; `row_flt_ls_is_spo_only` updated |
| F01 | `TI_IMCR_*` placeholders 0u, written by `lock_faults()` (IMCR[0] = 0). | `s32k396_board_cfg.h` (TODO(RM)) `#error`s in a target build until filled; filled values must be non-zero with two different IMCR indices (`_Static_assert`); nothing is written while unbound; `hal_pwm_fault_route_bound()` reads the IMCRs back. Host: UNBOUND, and an unbound route does not carry FLT to the PWM. | platform_cfg: `fault_route_unbound_by_default`; scenarios: `unbound_fault_route_never_arms` |
| F02 | `hal_pwm_config_locked()` true from an image read-back; REG_PROT was a TODO. | `hal_pwm_config_matches()` (image) and `hal_pwm_protection_locked()` (REG_PROT SLBR bits + GCR.HLB read back, generic S32K3 layout, offsets TODO(RM); false unless every bit reads set, false without hardware). `lock_faults()` sets the soft locks, then the hard lock. CTRL2 is not locked (its FORCE bit is written at every mode change); its INDEP bit is read back every tick instead. Host: a REG_PROT model rejects writes from any master after lock; an MCU reset unlocks until re-init. | platform_cfg: `regprot_lock_decision_needs_every_bit_read_back`, `protected_registers_reject_writes_from_cpu_and_dma`; scenarios: `watchdog_reset_relocks_before_rearming` |
| F06 | No arming evidence. | `safety/arm_evidence.c`: ROUTE_BOUND, CONFIG_MATCHES, PROTECTION_LOCKED, FAULT_ROUTE_VALIDATED, OVP_ROUTE_VALIDATED; the last two from `NV_REC_VALIDATION` (CRC-32, `TI_FW_ID`, SKU, device UID, measured FW-06 chain ≤ 15.6 µs). Incomplete ⇒ init FAIL (no FS0B release, no FW-16, no EN); read back every tick (a loss while armed goes through the §6 "control lost" row); INV_STATUS b15 = missing items. | calib: `validation_record_binds_image_card_and_crc`; scenarios: `arming_refused_without_evidence_and_the_status_names_it`, `arming_permitted_with_a_valid_record`, `arming_refused_on_record_identity_or_crc_mismatch`, `evidence_lost_while_armed_goes_through_section6` |
| F23 | Demag and circle clamps after field weakening, no voltage check: a finite infeasible (id, iq). | A final witness `torque_v_required()` ≤ `torque_v_available()` (Rs, Ld, Lq, ψ, ω_e, `cal_vdyn_reserve_frac` 5 %): reduce iq, then id toward the demag limit; `TQ_INFEASIBLE` if not even iq = 0 fits ⇒ zero torque, speed-limit request (b14.3), DTC_TORQUE_INFEASIBLE. | torque: `witness_motor_map_sweep_never_returns_an_infeasible_pair`, `field_weakening_holds_voltage_ellipse_and_demag_clamp` (tightened); scenarios: `infeasible_current_gives_zero_torque_speed_limit_and_dtc` |
| F24 | KCL misses a channel stuck at zero at zero current, below its tolerance, or all three stuck. | Activity check while modulating (`cal_isns_act_min_a` 20 A, `cal_isns_act_frac` 0.2, `cal_isns_act_debounce` 20), per channel and angle-aware; latched `stuck_fault` ⇒ currents invalid ⇒ "control lost" row, DTC_ISNS_STUCK. Window/range/stale checks unchanged. Coverage per operating state: `docs/traceability.md`. | current: `activity_catches_a_stuck_channel_where_current_is_asked`; scenarios: `all_three_current_channels_stuck_detected_under_command`, `one_current_channel_stuck_below_the_kcl_tolerance_detected` |
| 9 | A QDIS shorted with the battery connected bypasses the 5 s release (4 × 96 W) and showed only as a DTC at the next opening. | The unexpected-discharge verdict (QDIS not commanded, contactors open, bridge not modulating — new) latches "service required": no arming, INV_STATUS b14.1 (do not re-energise) and b14.2 (open the contactors), kept in NVM (`NV_REC_DTC`) and re-applied at every boot. | discharge: `unexpected_discharge_judged_only_with_nothing_drawing_on_the_link`; scenarios: `stuck_on_qdis_latches_service_required_and_never_rearms` |

Test infrastructure changed with it: the harness now generates phase currents per current-loop
sample as an ideal current loop in the controller's dq frame (it used to inject 0 A or a fixed
d-axis amplitude at the mechanical angle, which left the FOC saturated and the FW-10 rate check
never reached), provisions the route binding and the validation record, and INV_STATUS grew bytes
14–15 (`can_cmd.h`). Existing tests changed only in signatures (`br_init`, `st_step`, `dis_step`,
`hal_time_ms`) except `row_flt_ls_is_spo_only` and `field_weakening_holds_voltage_ellipse_and_demag_clamp`,
whose expectations follow A12-R08 and F23.

## Round 15 (rechecks of commit a8c75eb)

Two confirmed defects, same rule: **fail closed**. Each change has regression tests that fail on the
pre-fix source and pass now (method and per-test results: `docs/traceability.md`, "Round 15").

| ID | Defect | Change | Tests |
|---|---|---|---|
| A13-R04 | ADC channel class not propagated. Round 14 moved NTC_A to T15 = PTC11 = ADC5_S11 (a standard input), but `s32k396_adc.c` MAP[] kept a hand-written `'P'`: `S32K3_ADC_CH('P', 11)` = 11 selected PCDR11 of an 8-entry array (UBSan: out of bounds; the read returned the register after PCDR7) instead of ICDR11 (= 43). The schedule was hand-listed too: `hal_adc_start_slow()` started the normal chains of ADC0/3/4/5, so ADC1's injected chain — INTRLOK_N, TMOD_W and now MT2_SIG (moved to ADC1_P0, next to the continuous V_DC ch2) — never ran; and HW_ID (ADC3_P0, slow list) was classified in `app_init` before any slow list had run, from a "never converted" 0 (a false "HW_ID short" on the target). | `gen-board-map.mjs` emits the full triple `BP_<NET>_INST/_SUB/_CHAN` for every peripheral signal and refuses an ADC input that does not exist (P8+, S24+). MAP[] = `TI_ADC_MAP_INIT` (`s32k396.h`), one `TI_ADC_ROW(net, group)` per HAL input with all three from `board_pins.h`: no per-pin letter left. `S32K3_ADC_CH()` is strict (any other pair is `TI_ADC_CH_INVALID`), and `cdr()` reads only PCDR0–7 / ICDR0–23 (else "never converted"). The schedule is derived from MAP (`s32k396_cfg.h`: `adc_slow_chain`, `adc_chain_mask`): the 1 ms list starts each instance's chain (normal on ADC0/3/4/5, injected on ADC1); `hal_adc_init()` reads every chain's NCMR/JCMR back against the ball map and refuses a mismatch (a stale Config Tools project) or a mapped input on an instance it leaves off. `init_identity()` starts the slow list before each HW_ID sample. ADC1's ch2 gap is (1 + 3) conversions ≤ the 5 µs FW-06 allocation (checked from the params). `TI_FW_ID` 0x0A0D000F: a round-14 validation record measured the FW-06 chain with the old ADC1 schedule. | platform_cfg: `adc_map_matches_the_ball_map`, `adc_schedule_follows_the_ball_map`; scenarios: `hw_id_is_converted_before_it_is_classified` |
| A13-R02 (review 3) | Low-speed contactor loss. `detect()` raised the battery-lost row only for `(contactors != CLOSED) && (ti_absf(speed) >= n_x)`: at a known low speed or standstill an OPEN or INVALID report — and at any speed a stale one, which keeps the last CLOSED — raised nothing unless V_DC disagreed with the pack. `st_run()` set `arm` and `torque_enable` before its exits, so the invocation that left RUN still permitted the requested torque; the next ticks disarmed through PRECHARGE_WAIT with EN low: all gates off with whatever current the winding held. | Armed (ARMED_ZERO_TORQUE/RUN/DERATE) the battery path must be proven at every speed: contactors reported CLOSED in a fresh VCU frame; OPEN, PRECHARGE, INVALID and a stale report are all "lost" (and V_DC off the pack, as before). The §6 row decides: below n_x zero torque at the current-loop rate under current control while the winding current is ≥ `cal_spo_release_a` — a §6 permission that does not depend on the state's arm; FW-06 stays the OV backstop — then SPO with EN low; at n ≥ n_x or unknown speed LS-ASC; without current control or ASC the other rows and the energy rule apply as before. The row holds while that response energises the bridge, then clears: unarmed, open contactors are the precharge sequence. It is the FAULT state while the response has energy to manage; a loss met with nothing to manage (SPO at once, V_DC at the pack: the FW-08 zero-torque opening) is not (`fm_needs_fault_state(f, done)`). State-machine outputs describe the state an invocation ends in: leaving RUN/DERATE grants no torque (to FAULT, DISCHARGE or SAFE_POWERDOWN no arm either); an active battery-path row (`sm_in_t.battery_lost`) leaves RUN like an open contactor and blocks re-entry. | scenarios: `low_speed_open_contactor_is_a_battery_path_loss` (the reviewer's reproduction), `battery_path_loss_while_armed_at_every_speed` (zero/low/high/unknown × OPEN/INVALID/stale, 340 A rms, regenerating), `zero_torque_opening_at_standstill_disarms_without_fault` (guard), `stale_can_takes_torque_to_zero_not_held`; state_machine: `leaving_run_grants_no_torque_in_the_same_invocation`, `battery_path_row_leaves_run_and_blocks_reentry`; fault_mgr: `battery_lost_is_a_fault_until_its_response_is_done`; safe_state: `unknown_speed_takes_high_column` (battery row added) |

Test infrastructure: the host sim can model the target's slow list (`sim_adc_require_slow_start()`: only
the phase currents and V_DC are converted before the list is first started; off by default). Existing
tests changed: `stale_can_ramps_to_zero_not_held` became `stale_can_takes_torque_to_zero_not_held` (a stale
report under torque is now a battery-path loss: zero torque at the current-loop rate instead of the FW-11
ramp; it also checks the re-arm through precharge); `dtc_time_stamps_across_the_microsecond_wrap_in_the_application`
runs at zero torque (under torque the loss disarms and the timeout DTC stops being re-stamped); the
`fm_needs_fault_state()` call sites (signature).

## Round 16 (rechecks of commit 32214be)

Four confirmed acquisition defects, same rule: **fail closed**. Each change has regression tests that fail on
the pre-fix source and pass now (method and per-test results: `docs/traceability.md`, "Round 16").

| ID | Defect | Change | Tests |
|---|---|---|---|
| A14-R01 (rev. 2) | Resolver validity never expired. `sense_fast()` updated the resolver only when all three blocks were read, and nothing invalidated it when no new tuple came (`GAP_MAX_BLOCKS` ran only when a later block was consumed): valid stayed 1 a second later. | `rslv_age()` runs on every current-loop tick, frame or not: the newest coherent frame (its block start) may be at most `cal_rslv_hold_us` old (500 µs, range 250–800). Derivation (`gen-params.mjs`): the hold may add at most the angle error the observer already carries at the acceleration envelope, α/ω_n²; extrapolating adds e_ω·t + α·t²/2, with the critically damped observer's peak speed lag e_ω = α/(e·ω_n); the two are equal at t = 1.09/ω_n = 580 µs (300 Hz), whatever α; 500 µs adds 0.26° el at 2·10⁴ rad/s². Floor: two carrier periods + jitter (a loop faster than the frames reads nothing new every other tick — not a fault); ceiling: the observer's 8-block re-acquisition gap. Past the hold the angle is withdrawn (`stale`, DTC_RSLV_STALE) and the existing "resolver invalid" path takes the bridge (no ordinary FOC; SPO or PWM-ASC per §6); returning frames are acquired from scratch (priming + SETTLE_BLOCKS), the latched row needs a VCU fault reset below n_x. The last valid speed is held only for the §6 column (`cal_speed_hold_ms`, now independent of the resolver's lock: `rslv_seen`). | resolver: `validity_expires_without_new_frames_and_reacquires_from_scratch` (standstill and 3000 rpm, each also across the µs wrap); scenarios: `resolver_frames_stopping_withdraws_the_angle_at_the_hold` (0 rpm/200 Nm, 1000 rpm/100 Nm across the wrap, 10 000 rpm), `temporary_empty_reads_never_fault` (SiC 20 kHz, IGBT 10 kHz, COS 30 µs late); params: `round16_cal_defaults_and_ranges` |
| A14-R02 (rev. 2) | One SIN-DMA heartbeat vouched for three channels: the SIN completion published one count and one stamp for every reader, so a frozen EXC/COS buffer read as fresh, and a completion between the EXC read and the SIN/COS reads gave a mixed-epoch tuple carrying only the last stamp. | A frame protocol both platforms run (`src/hal/sdadc_ring.c`). Each SDADC's DMA has its own completion interrupt (three IRQs, `s32k_sdadc_dma_irq`) and a 4-slot ring; an epoch is published only once every channel has completed it, stamped by its FIRST completion; each count is checked against the channel's DMA write position (TCD destination address). A channel a block behind another, an interrupt that finds its DMA two blocks on, or lost samples break the block-to-epoch mapping: the ring stops publishing until re-init and the resolver ages out. `hal_sdadc_read_frame()` copies EXC + SIN + COS + epoch + stamp together under a seqlock, with every DMA position checked before (≤ 1 block past the epoch) and after (≤ 2) the copy and the copy shorter than a carrier period: the slot cannot have been rewritten even with the completion interrupts held off. Otherwise false, output untouched — a missing frame feeds A14-R01's age, never a fresh stamp. | sdadc (new suite): `every_frame_is_one_epoch_of_all_three_channels`, `a_frozen_channel_yields_no_frame`, `a_late_channel_holds_the_frame_back_and_the_stamp_is_the_first`, `a_completion_between_channel_reads_never_mixes_epochs`, `held_off_completion_interrupts_never_yield_a_fresh_frame`, `the_epoch_counter_wraps`; scenarios: `a_frozen_resolver_channel_is_never_read_as_fresh` |
| A14-R03/R04/R01 | Failed phase-current acquisition: the target `hal_adc_read_phase()` zero-filled a missing channel and left `*t_us` unwritten, and `sense_fast()` ignored the result and passed its uninitialised `t` to `isns_update()`. | HAL contract (`hal/adc.h`): all three new conversions of one trigger, or false with nothing written (the target driver fetches all three and writes only a complete triplet). The caller consumes only a complete triplet; otherwise `isns_lost()`: invalid, not fresh, no channel valid (the OC backstop and the activity check skip it), the stamp stays the last complete triplet's → the existing current-sensor path (§6 "control lost", DTC_ISNS_STALE — not an open wire); V_DC and the resolver are serviced in the same tick. A stopped BCTU raises no current-loop interrupt at all, so the 1 ms task now checks the loop's liveness: last ISR entry older than `cal_isns_stale_us` ⇒ currents lost, resolver aged. | current: `lost_sample_is_invalid_and_keeps_its_last_stamp`; scenarios: `lost_phase_current_triplets_take_the_failure_path` (all 7 combinations, repeated, recovery), `lost_triplets_across_the_microsecond_wrap_keep_a_defined_stamp`, `a_stopped_current_loop_is_caught_by_the_task` |
| A14-N01 / review 3 R04 | Amplitude planes: the excitation monitor taps the protected node (after RSX, before the PTC and the harness), not the resolver terminals, and the FW-10 target was an implicit EOL code count. | `cal_rslv_exc_target_vpp` = 7.2 V pp AT THE MONITOR PLANE, the trim setpoint; the FW-20 record carries the monitor chain's gain (`exc_code_per_vpp`, codes per V pp; layout 2). Planes (`gen-params.mjs`, A.15 exciter 13 k/28 k): amplifier = monitor × 77/72.6 = 7.64 V pp (1.91 V pk per output, under the 2.07 V pk −40 °C slew ceiling); SWG = 7.64/(2 × 2.072) = 1.843 V pp, 2.2 % under the MAXAPP low corner (1.884); winding = monitor × `cal_rslv_wind_per_mon` (70/72.6, PTCs cold) = 6.94 V pp; a PTC at 5 Ω for an hour after a trip gives 6.3 V pp, which the monitor cannot see. FW-10 now judges the WINDING — monitor × allowance × the resolver's own ratiometric output, which does see the PTC — against the 6.5 V pp floor: the post-trip state is flagged (DTC_RSLV_EXCITATION). `ti_params_validate()` refuses a setpoint beyond the low corner, the slew ceiling or the cold floor. The SWG starts at `cal_swg_code_init` (8: ≈ 1.45 V pp at the max corner) and ramps up one code per 5 ms, never from the register maximum; the excitation checks and validity wait for the ramp; `DTC_RSLV_SWG_SAT` when the trim sits at code 15 below its band. | params: `exciter_planes_and_trim_headroom`; resolver: `winding_plane_flags_what_the_monitor_cannot_see`, `swg_trim_ramps_readies_and_saturates`; calib: `each_failure_detected` (layout 1 refused); scenarios: `swg_trim_is_written_to_the_generator` (rewritten: three corners), `a_low_impedance_resolver_saturates_the_trim_with_a_dtc`, `ptc_post_trip_is_flagged_at_the_winding_and_a_cool_restart_recovers` |
| incidental | A never-acquired resolver raised the latched "control lost" row in FAULT (straight from INIT), and the unknown-speed §6 decision then raised MCU_GATE_EN for PWM-ASC in a no-arm state — latent: the resolver used to acquire in ≈ 2 ms, before the first FAULT tick; the SWG ramp now takes 20–35 ms. | The row needs a resolver that was valid once (`rslv_seen`); before its first acquisition nothing can arm (SENSOR_SELFTEST needs it). | the five no-arm scenarios (`hwid_wrong_open_short_never_arm`, `arming_refused_*`, `unbound_fault_route_never_arms`, `brownout_during_nvm_write_never_blocks`, `stuck_on_qdis_latches_service_required_and_never_rearms`) |
| incidental | FW-15 "no sooner than 1 s": the retry gate compared floored ms stamps (1000 counts can be 999.001 ms); a shifted sub-ms phase made `desat_retry_waits_1s_across_the_microsecond_wrap` reset at 999.76 ms. | One more count (`desat_retry_min_ms + 1`). | fault_mgr: `one_authorised_retry_after_1s_then_latch` (2000 refused, 2001 allowed); scenarios: `desat_retry_waits_1s_across_the_microsecond_wrap` |

Test infrastructure: the host simulation's resolver path is a per-channel eDMA model (each SDADC's DMA completes into
its own 4-slot ring and raises its own interrupt; `sim_sdadc_freeze/delay_ns/complete_now/irq_latency_ns/read_hook/
count_base/tag`) behind the card's excitation chain (SWG corner `sim_swg_maxapp`, MFB + bridge, RSX, PTC and primary
`sim_resolver_load`); `sim_adc_phase_stop()` stops phase channels. The harness's `exc_scale` is gone. Existing tests
changed: `swg_trim_is_written_to_the_generator` (rewritten for the ramp and the planes), `one_authorised_retry_after_1s_then_latch`
(boundary 2000 → 2001 ms), `each_failure_detected` (layout 2), the resolver unit tests' calibration (monitor gain) and
`feed()` (marks the excitation ready: the trim is tested on its own). `TI_FW_ID` 0x0A0F0010 and FW-20 layout 2: this
image needs a new EOL/HIL validation record and a new calibration record before it arms.

## Round 17 (closure of the open items)

Every item of the former list of "contract contradictions and open items" is closed: the contract now states
the implemented decision, or the item is a row of the target checklist (the list below says which). Two
decisions changed the image's behaviour, and three more changes came in the same round: the FS26 answer cadence
(found on the way), the ASC-exit release wait and the LV supply supervision (both from the qualification-plan
review). Each has regression tests that fail on the pre-fix source and pass now (method and per-test results:
`docs/traceability.md`, "Round 17").

| Item | Before | Change | Tests |
|---|---|---|---|
| 26 — FW-08 DC-link trim | Under the battery-lost row below n_x, iq was held at 0 at the current-loop rate while `t_cmd_nm` carried the DC-link PI output (V_ref = the normal-range maximum): the trim never reached iq, id still took the MTPA/field-weakening value of that output (−52 A at 7000 rpm), and INV_STATUS reported it as the torque (−50 Nm with the link at 750 V; +17.5 Nm with the zero-torque bit clear at 870 V). RUN had no trim at all. | Decided: under the row the inverter applies zero current, id = iq = 0 at the current-loop rate (`SS_ACT_ZERO_CURRENT`), and INV_STATUS reports the 0 Nm applied. The trim (`dcl_trim`) runs only in normal RUN/DERATE — torque granted, so the battery path is proven — as a regen limiter: its reference is `vdc_max_v` by construction, it takes regen back while V_DC is above it (at most `cal_dcl_tmax_nm`), never adds motoring torque, and is reset outside RUN. | dclink: `trim_takes_back_regen_only_above_the_range_maximum` (rewritten); scenarios: `dc_link_trim_limits_regen_with_the_battery_present`, `battery_path_loss_below_n_x_applies_and_reports_zero_current` (1000 rpm with the link above the range, 7000 rpm in field weakening), `battery_path_loss_while_armed_at_every_speed` (tightened: t_cmd 0, id 0 below n_x) |
| T-32 — FS26 watchdog cadence (found in this round) | The answer came after the slow list and CAN, due at ≥ 2000 µs from a stamp taken after its SPI transfer: on the target's exact 1 ms grid that first holds on the third task, so the FS26 was answered every ≈ 3.0 ms — the end of its window (3 ms, 50 % closed, fail-safe oscillator 20 MHz ± 5 %: open until 2.857–3.158 ms). At a fast FS26 the answer is late and one late answer reaches WD_ERR_LIMIT = 2: FS0B, DRV_EN low. The host harness hid it: its relative time steps let every SPI transfer shift the later ticks (2.03 ms). | The answer first in the 1 ms task, due at ≥ 1500 µs (`fs26_wd_due`): every second task, 1890–2110 µs apart by design (an answer offset of 20–130 µs), inside the window with 311 µs / 747 µs margin at its two ends (contract §5, "FW-12 refresh cadence"; `docs/timing.md`). The harness keeps the target's two clocks; the FS26 model has the oscillator tolerance. | scenarios: `fs26_is_answered_every_2ms_inside_its_window_at_both_oscillator_corners` (−5 / 0 / +5 %) |
| 19 — service lock | "Service required" (stuck-on QDIS) survived key cycles in NVM with no way to clear it. | FW-32: a UDS server on the diagnostic bus (`comms/uds.c`, single-frame ISO-TP, request 0x7E1 / response 0x7E9): SecurityAccess 0x27 (4-byte seed/key; the key function is the build-time hook `TI_UDS_KEY_FN`, **none by default: every seed request NRC 0x22, the lock cannot be cleared**; one key per seed; three invalid keys lock SecurityAccess out until the MCU restarts) and RoutineControl 0x31 start of 0xF010 (NRC 0x33 without the unlock; NRC 0x22 with HV present or unknown, or the bridge armed). The routine rewrites the NVM record as CLEARED with the key cycle and sets `DTC_SERVICE_LOCK_CLEARED`; the clear takes effect at the next power-up (this key cycle keeps the lock). | uds: `security_access_refused_without_a_key_function`, `seed_key_unlocks_one_routine_run`, `wrong_keys_lock_out_and_malformed_requests_are_refused`; scenarios: `service_lock_clear_is_refused_without_a_key`, `service_lock_clear_is_refused_with_hv_present_or_armed`, `service_lock_clear_with_the_key_takes_effect_at_the_next_power_up` |
| FW-06a — ASC exit | After its 1 µs ASC_CLR pulse the firmware waited 1 µs, so the first high-side pulse came 2.0 µs after the clear's falling edge — before the low sides' ASC release (≤ 1.07 µs: design-verify Safety A.8, VOW3120 t_pHL 0.5 + DASCR 0.08 + NSI6611 t_ASC_f 0.48 µs + 11 ns of logic) plus their turn-off (the dead time, 1.0 µs SiC / 2.5 µs IGBT): deadlines 2.07 / 3.57 µs. The contract still quoted 7.5 / 0.75 µs for the ASC entry/release. | The first HS pulse waits `cal_asc_release_ns` (1.5 µs; range 1.07–5 µs, never below the release) + the SKU dead time from the falling edge, + one µs timer count: 4.0 µs SiC, 5.0 µs IGBT on the host. The contract's ASC figures follow the verifier row: LS start ≥ 4.42 µs, entry ≤ 7.56 µs, release ≤ 1.06 µs (1.07 µs with the logic). | bridge: `asc_exit_only_when_allowed_and_hs_after_the_release`; scenarios: `asc_exit_first_high_side_pulse_after_the_release_deadline` (after an MCU reset at 10 000 rpm, SiC and IGBT) |
| FW-33 — LV supply (let-through LV entry) | The firmware did not read VSUP: a load dump or a jump start left no record, and an overvoltage of any length was never acted on (the FS26's VSUPOV is only an interrupt, and INTB is unused). | VSUP through the FS26 AMUX (VSUP / 14, set at every boot), every 1 ms. Above 20 V is information — RUN and the torque unchanged (no derate), `DTC_LV_OVERVOLTAGE` stamped over the event — for `cal_vsup_ld_ms` (500 ms, range 400–1000) above `cal_vsup_jump_max_v` (27 V, range 24.5–30: IR-03 test B, 35 V / 400 ms) and for `cal_vsup_jump_ms` (65 s, range 60–120 s) at or below it (IR-02, 24 V / 60 s). Longer is `DTC_LV_OV_SUSTAINED` and the §6 command-lost ramp — the HVIL-open path — until KL30 is back. | scenarios: `lv_load_dump_35v_for_400ms_is_information_not_a_fault`, `lv_overvoltage_beyond_its_band_takes_the_orderly_ramp`, `lv_24v_jump_start_is_information_for_its_60s` (24 V and 26.5 V) |

`TI_FW_ID` was 0x0A0F0011 in round 17 (0x0A0F0012 round 18, 0x0A0F0013 round 19, 0x0A0F0014 the round-23 torque-solver image, **0x0A0F0015 since the round-23 gap closure, 0x0A0F0016 since round 24** — the current image): every change of the ID needs a new EOL/HIL validation record before it arms (checklist T-05);
the calibration record stays layout 2. It was introduced in this round and never validated, so the FS26,
ASC-exit and LV changes ship under the same identity. Also in this round: the markers of the platform code were consolidated to one per
bring-up item (47, each a row of `docs/target-bringup.md`; `make target-check` fails on drift either way), the
parameter sets regenerated (`make params`: 174 fields, 75 CAL rows — the DC-link trim's comments, the ASC
release and the three LV bands), the harness's plant given ADC-level noise (`docs/traceability.md`, "Round 17"),
and the ball-map test states the V5GD pin as the contract now does.

## Round 18 (rechecks of commit 4425af9)

Three confirmed defects, verified against the source before the change, same rule: **fail closed**. Each change has
regression tests that fail on the pre-fix source and pass now; each fix was also mutated once and the suite caught it
(method, per-test results and the mutations: `docs/traceability.md`, "Round 18"). Contract §10d: FW-34…FW-36.

| ID | Defect | Change | Tests |
|---|---|---|---|
| A16-R01 (FW-34) | Fresh samples declared stale on the target. `app_isr_current()` read `now_us` at entry; the target's `hal_adc_read_phase()` and `hal_adc_read()` stamp a sample with `hal_time_us()` when they read it — later — and `isns_update()`/`vdc_update()` computed the age `now_us − stamp` unsigned: one tick newer read 4.29e9 µs old, the currents and V_DC stale, the control lost. `rslv_age()` the same for a frame an SDADC interrupt published inside a long ISR. The host hid it: its reads stamped with the frozen clock, the ISR's entry. Found at another caller of the same comparison: the 1 ms task's FW-31 liveness check compared its start time with `t_isr_us`, which the current-loop ISR rewrites when it preempts the task (after the task read its time, during its FS26 transfers): "loop dead", the currents lost, the control-lost row. | Each freshness check reads its own time after its acquisition reads (`sense_fast`: the triplet; VOFS, V5GD, then V_DC — the checked channels last; the frame). A signed-safe helper `ti_stale(now, stamp, hold)` (`ti_types.h`): stale when the stamp is `hold` or more before now — or `hold` or more after it (no ISR's execution reaches that: a corrupt stamp is refused either way); wrap-safe; used in `isns_update`, `vdc_update`, `rslv_age` and the task's liveness check. `ti_elapsed()` stays unsigned for timers. The ISR's entry time stays its own: `t_isr_us`, the WCET reference, the FOC angle, the bridge. The same class at the FW-15 recovery timer: `br_rec_step()` timed the ≥ 1.5 ms low with the task's `now_us` against the fault ISR's newer stamp — with the DESAT hold over before the recovery started in that tick, the age wrapped and the reset pulse came ≈ 0.1 ms after the fault (the driver not reset: `DTC_FLT_RECOVERY_FAIL`); it now takes no time argument and reads its own (the FW-22 rule). The host models the target's order: `sim_adc_read_delay_ns()` (each read takes simulated time, events included, before it stamps) and `sim_fs26_xfer_hook()` (an interrupt inside the task's FS26 transfer). | time: `sensor_stamps_are_judged_with_a_signed_age`; current: `a_triplet_stamped_after_the_check_time_is_fresh`; vdc: `a_channel_stamped_after_the_check_time_is_fresh`; resolver: `a_frame_newer_than_the_check_time_is_not_aged_out`; bridge: `fw15_low_wait_runs_on_the_bridges_own_clock` (also across the µs wrap); scenarios: `samples_stamped_after_the_isr_entry_stay_fresh` (1 / 5 / 50 µs per read, across the µs wrap), `a_run_at_speed_with_the_adc_reads_taking_time`, `a_current_loop_preempting_the_task_is_not_a_dead_loop`, `fw15_low_wait_counts_from_a_fault_that_preempted_the_task` |
| A16-R02 (FW-35) | The resolver stamp came from the completion interrupt's execution time: `t_start = now_us − period` in `hal_sd_ring_complete()`, so an interrupt served late stamped old data too new (100 µs at 10 kHz is 24° el at 10 000 rpm, 4 pole pairs); blocks since the last count were `(hw − done) % 4`, so an interrupt exactly one lap (4 periods) late read as a repeated one, and the reader's DMA-position checks were modulo 4 as well: a lap was invisible. A broken ring stayed down until reset. | The stamp is cadence-locked: block k starts at `t_org + (k − k_org)·100 µs` (unsigned, wrap-safe), the origin anchored at the first completion after (re)acquisition and moved back by any completion that comes before its block's end (a completion is never early). A block's first completion must be served within `cal_sd_irq_lat_max_us` (new CAL: 30 µs, range 5–45 µs, below half the carrier period; `docs/timing.md`), a later channel's within half a period, else the timing is ambiguous: the block is not published and the ring breaks. The reader refuses a slot the cadence says may have been rewritten (a copy ending ≥ 3 periods after the block start). A broken ring re-acquires by itself: at a completion that finds all three DMAs in one slot (TCD destination addresses on the target, `s_dma[].hw` on the host) it takes that count, numbered past every published epoch, and anchors a fresh origin at the next completion; the resolver bridges a short gap or re-primes through FW-28; each re-acquisition is one occurrence of the information DTC `DTC_RSLV_REACQUIRED` (no §6 row). Lost samples (`TI_SD_LOST`) keep the ring down until re-init — positions cannot restore carrier phase 0. The SDADC data rate and the STM share the PLL (assumption, `docs/timing.md`; T-40). | sdadc: `interrupts_held_off_within_the_deadline_keep_every_stamp_exact`, `a_late_anchor_is_moved_back_by_the_first_prompt_completion`, `an_interrupt_held_off_past_the_deadline_is_rejected_then_reacquired` (40, 60 µs), `interrupts_held_off_for_a_lap_are_detected_never_fresh`, `one_channel_lapping_while_the_others_do_not`, `all_three_stalled_together_are_detected_and_reacquired`, `the_reader_preempted_across_a_lap_never_returns_the_frame`, `stamps_are_exact_across_the_microsecond_and_epoch_wraps`, `lost_samples_keep_the_ring_down_until_init`; params: `round18_cal_defaults_and_ranges`; scenarios: `a_late_resolver_interrupt_at_speed_is_counted_and_reacquired` (SiC, IGBT) |
| A16-R03 (FW-36) | `rslv_theta_e_at()` subtracted the chain latency: `(now − t_ref) − t_mid − cal_rslv_latency_us`, while the parameter is a positive delay (the block's angle is the rotor's that long before its mid-block reference): −12 / −24° el at 10 000 rpm, 4 pole pairs, 25 / 50 µs. The unit test encoded the wrong sign. | The latency is added: θ(now) = θ_block + ω·((now − t_ref) − t_mid + L); the header comment, the generator's description ("positive = the sample represents an earlier instant; add"), `docs/timing.md` and the T-37 row (the HIL measurement's sign convention) say so. | resolver: `latency_compensation_matches_the_true_angle_at_now` (an independent rotor model: both directions, 3000 / 10 000 rpm, 25 / 50 µs), `acquires_at_speed_after_a_reset` (corrected) |

`TI_FW_ID` was 0x0A0F0012 for this round-18 image (0x0A0F0013 round 19, 0x0A0F0014 then 0x0A0F0015 in round 23): each image needs a new EOL/HIL validation record before it arms (checklist T-05); the
calibration record stays layout 2. The parameter sets were regenerated (`make params`: 175 fields, 76 CAL rows);
the target checklist gained T-40 (the completion-interrupt latency distribution and the cadence against the STM),
and T-37 states the latency's sign convention. Existing tests changed: `resolver: acquires_at_speed_after_a_reset`
(the corrected sign); `bridge:` the three FW-15 tests' calls (`br_rec_step()` lost its time argument); `sdadc: a_frozen_channel_yields_no_frame`, `held_off_completion_interrupts_never_yield_a_fresh_frame`
and `scenarios: a_frozen_resolver_channel_is_never_read_as_fresh` (a ring that broke now re-acquires once its
channels are in step — it used to stay down until reset; a channel resuming out of step still never does);
`sdadc: the_epoch_counter_wraps` (37 frames: the ring takes the DMA positions at its first completion and anchors
at the second); every `sdadc` test now also requires each frame's stamp to be its carrier period's true start
(± 1 µs), not only its three tags to agree.

## Round 19 (rechecks of commit e315bf1)

One confirmed defect — all three rechecks reproduced it (A17-R01, register F201) — verified against the source before the
change, same rule: **fail closed**. The regression tests fail on the pre-fix source (108 checks in 17 tests) and pass now;
every mechanism was mutated once and the suite caught it (method, per-test results and the mutations:
`docs/traceability.md`, "Round 19"). Contract §10d: FW-35 rewritten.

| ID | Defect | Change | Tests |
|---|---|---|---|
| A17-R01 (FW-35) | The resolver ring dated its cadence from a completion callback's own execution time (`sdadc_ring.c` 147–150: `t_org = now_us − period_us` at the first completion after (re)acquisition, moved back by an earlier one). A late anchoring callback became the reference: block 1 stamped 29–800 µs too new with the ring unbroken (80 µs = 19.2° el at 10 000 rpm, 4 pole pairs); a constant 40 / 60 µs delay passed the 30 µs deadline forever (every frame 40 / 60 µs too new); after a break the re-anchor absorbed the very delay just rejected (at the application: the FOC angle 5.3° el behind at 10 000 rpm); `resync()` took its counts from equal DMA slots modulo 4, never the acquisition phase; and an early completion moved the origin to itself. | The origin is the **SWG start**: the SDADCs are triggered by the SWG period start, so `hal_swg_start()` (both platforms) brackets the generator enable with two `hal_time_us64()` reads inside PRIMASK and anchors the ring (`hal_sd_ring_anchor`: t_org the later read, k_org the first carrier period's block, uncertainty u = the bracket + 1 µs + `cal_swg_start_lat_us`, new CAL 2 µs [0, 20], T-42; u ≥ a quarter period is `lost`); running, it only changes the amplitude. The ring never anchors itself (an unanchored ring counts nothing) and judges EVERY completion against the absolute cadence, u added on both sides: a block's first completion within [−u, `cal_sd_irq_lat_max_us` + u], a later channel's within [−u, T/2 + u]; early or late breaks the ring. `t_org += late` is gone. A broken ring **re-syncs from the clock** — the counts are the block that ended within [−u, T/2 + u] of the completion — the DMA positions only confirming them (every DMA past it; a later channel still on it waits for its own completion); the completing DMA behind one past the block, a DMA elsewhere, or four periods without agreement is a DMA out of phase: `lost`, as are the platform's DMA error, FIFO-overrun and trigger-miss flags (T-41). A lost ring stays down until the **synchronized producer restart** `hal_sdadc_restart()` (DMA rings re-armed, the SWG restarted at its present code and re-anchored), which the 1 ms task requests at most `cal_rslv_restart_max` (new CAL: 3 [0, 10]) times per key cycle — counted in the retained session, so an MCU reset inside the key cycle does not refill it — each one occurrence of `DTC_RSLV_REACQUIRED`; beyond it the resolver stays invalid (FW-28). Times are 64-bit: the clock-derived index holds across the 32-bit wrap and any silence; the origin is re-based by whole periods at each publication. The host simulation triggers the DMA blocks from the SWG start and anchors as the target does (`sim_swg_start_latency_ns()`). | sdadc: `the_first_completion_is_judged_against_the_swg_start` (0, 29, 30, 31, 33, 34, 40, 60, 80, 800 µs), `the_swg_start_latency_stays_inside_the_declared_uncertainty` (1–3 µs), `a_constant_completion_delay_is_never_published` (40, 60 µs), `a_rejected_delay_is_never_absorbed_after_a_break`, `a_channel_paused_one_period_is_lost_not_taken_for_a_late_one`, `a_late_interrupt_inside_the_origins_uncertainty_is_no_phase_loss`, `an_early_completion_breaks_the_ring`, `the_origin_and_the_clock_index_hold_across_the_32bit_wrap`, `the_anchor_refuses_an_origin_too_uncertain`, `nothing_counts_before_the_swg_start`; params: `round19_cal_defaults_and_ranges`; scenarios: `a_late_completion_after_a_break_never_dates_the_angle`, `resolver_producer_restarts_are_bounded_per_key_cycle` |

`TI_FW_ID` was 0x0A0F0013 for this round-19 image (0x0A0F0014 then 0x0A0F0015 in round 23): each image needs a new EOL/HIL validation record before it arms (checklist T-05); the
calibration record stays layout 2. The parameter sets were regenerated (`make params`: 177 fields, 78 CAL rows; the
`cal_sd_irq_lat_max_us` description now says its reference is the carrier boundary, so the SDADC's output latency counts
in it). The target checklist gained T-41 (every SDADC/eDMA flag of lost or shifted samples wired to `lost`, and the
restart path of `hal_sdadc_init()`) and T-42 (the SWG start latency, the first block's phase 0, LDOS updates keeping the
boundaries, the SGEN flags); T-40 now measures the completion latency from the carrier boundary; T-28's lost samples wait
for the restart. Existing tests changed: `sdadc: a_frozen_channel_yields_no_frame` (a frozen channel is `lost` — found
behind the clock during the freeze — and nothing comes back without the restart; round 18 re-acquired the in-step
resume), `all_three_stalled_together_are_detected_and_reacquired` (the 5-period DMA stall is `lost`, then the restart; the
8-period one and the held interrupts re-sync), `a_completion_between_channel_reads_never_mixes_epochs` (the DMAs moving
on during the copy are now a 2 µs preemption across a boundary with the interrupts pending — the forced early completion
it used is refused now), `a_late_channel_holds_the_frame_back_and_the_stamp_is_the_first` (the stamp exactly the block
start), `the_epoch_counter_wraps` (+ the re-base invariant), `lost_samples_keep_the_ring_down_until_init` → `…until_a_restart`;
`a_late_anchor_is_moved_back_by_the_first_prompt_completion` removed — it proved the round-18 origin correction, which is
gone (its case, a 25 µs latency from the start, is inside the first-completion sweep: exact stamps from the first frame);
every `sdadc` test now requires each frame's stamp within ± 3 µs of its period's true start on the SWG's cadence;
`scenarios: a_frozen_resolver_channel_is_never_read_as_fresh` (lost, one restart, one DTC occurrence, no ring
re-acquisition; each iteration a cold start), `resolver_frames_stopping_withdraws_the_angle_at_the_hold` (comment: the
re-sync or the restart). Test infrastructure: `h_rotor_theta_e()` in the harness.

## Decisions recorded in the contract (round 17)

The former "contract contradictions and open items", by number. Each is now contract text (the section named,
in `docs/firmware-contract.md`; §10c indexes the round) or a checklist row (`docs/target-bringup.md`).

1. **V5GD pin** — FW-07: V5GD_SNS = V5GD/2 on PTD27 (ADC4_P6); PTB5 is RDY_LS (`test_board_map`).
2. **FW-05 fault path** — FW-05: analog watchdog → TRGMUX/LCU → eFlexPWM_1 FAULT1, high sides only; the eTPU
   wording is superseded. Silicon: T-08…T-10.
3. **Current-loop rate** — §2: 2·f_sw, double update (20/16 kHz SiC, 10 kHz IGBT).
4. **State order** — §9: GATE_SELFTEST before PRECHARGE_WAIT (the VCU precharges after "self-test done").
5. **FW-07 low-voltage floor** — FW-07: max(5 %, `cal_vdc_disagree_floor_v` = 18 V).
6. **FW-12 "OTP readback"** — §5 "FW-12 read-back and release": M_PROGID, OTP_CORRUPT, DBG_MODE, the INIT registers
   and complements at every boot; the per-field OTP comparison is EOL (T-34).
7. **FW-05 safe state** — FW-05: high sides off by FAULT1, then the §6 "control lost" row, cleared by a VCU reset
   below n_x.
8. **§6 gaps** — §6: the row "V_DC invalid with V5GD healthy" (SPO under the energy rule, else LS-ASC) and "Unknown
   speed" (the last valid speed held `cal_speed_hold_ms`, then the n ≥ n_x column, rule (a) at n_max) — round 23
   (fix 6): replaced by a physical bound, |n_last| + `cal_speed_accel_max_rpm_s`·t, unknown past n_max (contract §6).
9. **FW-04 recovery time** — FW-04: `cal_peak_recovery_s` = 180 s; unknown coolant temperature ⇒ no peak.
10. **FW-19 τ check** — FW-19: the plateau (97.5 % of the pack) is primary, τ the second signature.
11. **FS26 release** — §5 FW-12 paragraphs: release only at FLT_ERR_CNT = 0 within the self-test window; the answer
    cadence (fixed in round 17). Silicon: T-32 (answer arithmetic and spacing), T-33 (after an MCU reset).
12. **Lost DESAT record** — §7 step 1: A/B record; a brown-out that also loses retained RAM loses that one
    record — accepted, a short still present is recorded at the next DESAT.
13. **BMS timeout** — FW-11: zero regen only; motoring keeps the FW-03 envelope.
14. **FW-21** — §10 FW-21: the bootloader + HSE deliverable, not the application image's.
15. **FW-08b wording** — FW-08b as implemented: `keep_hv` at any speed while an SPO relies on the battery, until
    rule (a) holds or ASC; "no safe state proven" without the battery.
16. **Immediate MCU_GATE_EN low** — §4c (V5GD) and §7 step 1: with a FLT line low the drop waits
    `cal_desat_en_hold_us` (60–160 µs after the ASC_CLR); with FLT high it is immediate.
17. **IMCR "distinct" values** — FW-24: non-zero values, two different IMCR indices; the SSS values may be equal.
18. **`br_service(now_us)`** — FW-22: the hold starts from the bridge's own time read after the FLT lines.
19. **Service lock** — implemented (above): FW-32 (§10c); the product key: T-35.
20. **Dynamic voltage reserve** — FW-03/FW-25: `cal_vdyn_reserve_frac` = 5 % of the FOC voltage limit.
21. **REG_PROT layout** — checklist T-03 (layout, XRDC fallback), T-04 (the IMCRs, byte locks).
22. **Validation record producer** — checklist T-05; the contract's vehicle-interface paragraph (§10a) names it.
23. **Equal gain errors** — FW-05 addendum (§10a): bounded by the EOL record, the compare built from the same gains
    and DESAT; the coverage table is in `docs/traceability.md`.
24. **FW-11 vs §6** — FW-11 row and the §6 command-lost row: armed, a stale command is also the battery-lost row,
    which wins; the FW-11 ramp remains for a command lost with the battery path proven.
25. **When the battery-lost row applies** — FW-08: every 1 ms in ARMED_ZERO_TORQUE/RUN/DERATE; a FAULT only while
    its response still holds energy.
26. **DC-link trim** — implemented (above): FW-08.
27. **ADC1 injected chain** — FW-06 (the sample wait: 4 µs of the 5.0 µs row); measurement: T-11.
28. **BCTU list read-back** — checklist T-12.
29. **Image identity** — §10c: `TI_FW_ID` 0x0A0F0016 (round 24 — 0x0A0F0015 the round-23 second image, 0x0A0F0014 the round-23 torque-solver image; 0x0A0F0011 round 17, 0x0A0F0012 round 18, 0x0A0F0013 round 19), calibration layout 4 (round 23's FW-45/FW-46: the L_d/L_q saturation maps and the ripple table; 190 fields / 91 rows; layout 3 since the gap closure, layout 2 before); the records: T-05, T-06, T-07 (round 18:
    0x0A0F0012, round 19: 0x0A0F0013, §10d; round 23: 0x0A0F0014, FW-37, §10e; then 0x0A0F0015, FW-38…FW-44 and §10k).
30. **Amplitude planes** — FW-30 (round 17): the setpoint at the monitor, the floor at the winding through
    `cal_rslv_wind_per_mon` and the EOL ratio; the EOL confirmation: T-07.
31. **Where RSX sits** — FW-30: on the amplifier side of the monitor tap (77/72.6 up, 70/72.6 down).
32. **Exciter gain** — FW-30: |H(10 kHz)| ≈ 2.07 (2.072) for the 28 k feedback, 1.843 V pp from the SWG, 1.91 V pk
    per output.
33. **SWG code law** — FW-30 and checklist T-31.
34. **First acquisition** — §9 step 3 and FW-30: 20/25/35 ms at the high/typical/low MAXAPP corner; after an MCU
    reset at speed the speed is unknown for that time and ASC is kept.
35. **Current-loop liveness** — FW-31 (§10c).

**Silicon / RM checklist → [`docs/target-bringup.md`](docs/target-bringup.md).**

## Round 23 — VESC gap closure (FW-38 … FW-44)

The comparison in `docs/firmware-vs-vesc.md` (round 23) ranked the capabilities the VESC firmware has and ours lacked that a
traction inverter genuinely needs. Each is a numbered contract item with its own section below (the agents that implemented
them append here; counts are updated once at the end of the round).

### FW-38 — Firmware update: signed images, anti-rollback, the no-torque update state
FW-21's requirement implemented (contract §10f): nothing is installed or started unless an Ed25519 signature by the
release key, the payload's SHA-256, the target SKU and the anti-rollback security version all hold — the opposite of
VESC's CRC-only loader (`docs/firmware-vs-vesc.md`, gap 1).

| Part | Files | What it does |
|---|---|---|
| Container | `src/boot/image.h`, `tools/sign-image.mjs` | 128-byte header: magic "TIFW", format, target (SKU), length, `TI_FW_ID`, security version, SHA-256 of the payload, Ed25519 signature over the first 64 bytes. The tool builds (`--in --out --key --target --fw-id --sec-ver`), verifies (`--verify`) and prints a public key as a C list (`--pubkey`); Node's standard library only |
| Check | `src/boot/verify.c`, `sha256.c`, `ed25519_tweetnacl.c` | structure → signature → target → security version ≥ the counter → hash (read back from flash), each refusal its own `IMG_ERR_*`. Ed25519 vendored from TweetNaCl (public domain; origin and every change in its header), RFC 8032's S < L added, no UB (the negative shifts are multiplications); verification only in a target build. The key: a `const` table (host: the TEST key), overridden by the OTP/HSE copy (`hal_flash_pubkey`); none or all-zero ⇒ nothing verifies |
| Update state | `src/boot/update.c`, `uds_update.c`; one line in `src/comms/uds.c`; `src/app/app.c: update_conditions, update_enter` | 0x10 0x02 only disarmed, discharged, at standstill (else NRC 0x22, nothing changes); entering withdraws `ARM_EV_VALIDATED` and forbids arming until the next power-up (`DTC_FW_UPDATE`): no arming, no torque. 0x34 (needs the 0x27 unlock), 0x36 (counter, repeat, length, size, busy), 0x37, 0x31 0xFF01 verify / 0xF038 activate, 0x11 — flash work in `app_idle`, never in the 1 ms task |
| Bootloader decision | `src/boot/boot.c`, `nvm/nvlog.h: NV_REC_BOOT` | a write-ahead boot record (card SKU, anti-rollback counter, last-known-good flag, last outcome): ACTIVATE → verify STAGE → INSTALL → EXEC verified → TRIAL; the image confirms itself after 5 s (`UPD_CONFIRM_MS`) → the next reset commits it to LKG and raises the counter; an unconfirmed trial, an interrupted install or an invalid EXEC restores LKG; nothing valid ⇒ nothing starts |
| Flash | `src/hal/flash.h`, `platform/host/sim_flash.c` (+ `sim_flash.h`), `platform/s32k396/s32k396_flash.c` | three regions (EXEC, STAGE, LKG), page erase, word program into erased bytes only; the host model cuts power after any number of writes (the torn operation half-done, every later one failing); the target is a stub that fails every operation (T-44…T-47) |

**Keys.** The host tests sign with a TEST key pair derived from a public string (seed = SHA-256("TI FW-38 TEST KEY - NOT
FOR RELEASE"), `sign-image.mjs --key test`); its public half is the host build's key table and a target build can never
contain it. The release key pair is generated offline (an HSM or an air-gapped signing station); its private half never
enters this repository or a build machine — the release build receives only the public half (`-DTI_FW38_PUBKEY=` the
`--pubkey` output) or reads the HSE/OTP copy (T-46). An HSM signs the same 64 bytes the tool signs.

**Tests** (`tests/test_update.c`, 16 tests, 351 checks): SHA-256 (FIPS 180-4, one million 'a' incrementally) and Ed25519
(RFC 8032 test 1: key, signature, verification; the message, R, S, the key each flipped; S + L refused); the tool's
container verified and reproduced byte for byte; every refusal with its reason (signature, tampered payload and its last
byte, a signed field changed, another key, wrong target, rollback, each structural field, a read failure); 3000 bounded
random headers (the parser accepts exactly the structurally valid ones, nothing unsigned verifies) and one bit flipped in
each header byte (always refused); install → trial → commit with the counter (and the old image then refused as a
rollback); refusals that leave EXEC untouched; a power cut at every write of the swap (the last known good boots), a
second cut during the restore, the INSTALL record write torn (nothing copied yet) and the TRIAL write torn (abandoned);
an unconfirmed first boot rolled back; a cut at every other write of the commit (resumed, the counter at 6); a torn
record write never takes the counter back; EXEC corrupted (restored), both copies corrupted and an unsigned EXEC with no
record (nothing starts); the programming services' protocol; refused while moving, with HV present, armed, and armed
with the link reading 20 V; the update state never arms under a VCU enable and 100 N·m (INV_STATUS b15); an update end to
end over UDS (download, verify, activate, ECUReset, the bootloader, the self-confirmation, the commit, then arming), and
one whose first boot never confirms (rolled back, `DTC_FW_FALLBACK`). **Mutations** (14, each caught): the rollback, hash,
signature and target checks removed; an interrupted install rolled forward; the copy before the INSTALL record; the
arming not withdrawn; standstill not required; the entry conditions not checked; the block counter not checked; S < L
removed; the record ending in its own CRC-32 again; the counter not raised; the trial never confirmed.

**Found on the way.** A record that ends in its own CRC-32 makes the NVM slot's CRC-32 blind to it (CRC-32 over
M ‖ CRC-32(M) is the same for every M): a torn write validated with the stale bytes left in the slot, the record from two
writes back — an anti-rollback counter could go back. The boot record has no CRC of its own. **Open, outside FW-38:**
`calib_t` (FW-20) and `arm_validation_t` (FW-24) have that layout (contract §10f, open 1); an updated image needs its
own FW-24 validation record before it arms (open 2). The NVM's 32 slots are now all used. (Round 23 fixes 9 and 10 close
open 1 and the slot count; fix 11 carries TransferData over ISO 15765-2 — see "Fixes" below.)

**Host vs target.** The host proves the logic end to end: the check, every refusal, the UDS services, the update state's
interlocks through the application's arming evidence, and the bootloader's journal under power cuts on page-accurate
flash and A/B NVM models. Only the target proves the C40 driver and the region map (read-while-write, no ISR stall), the
release key in the HSE/OTP, the reset, the bootloader binary with its FS26 handling and timing, the HSE secure boot, the
debug lock and a monotonic counter in the HSE, and the EOL provisioning (T-44…T-50).

### FW-39 — Motor self-commissioning in an interlocked service mode

The service tool identifies R_s, L_d, L_q, ψ and the resolver's electrical zero (with the resolver's direction) on the
vehicle's own inverter — the capability the VESC firmware has — but through the safety chain instead of around it, and
nothing it measures is used before the next key cycle has validated it (contract §10g).

| Part | What it does | Where |
|---|---|---|
| Entry | the FW-32 SecurityAccess unlock (one start per unlock) + the tool's rig attestation (`LK` locked rotor / `DF`, `DR` dyno direction) + armed through the normal path (ARMED_ZERO_TORQUE, bridge armed idle, FW-24 evidence and the FW-20 record behind it) + no §6 row, no active DTC, a fresh VCU command without enable, the VCU's vehicle speed valid and zero, V_DC in the SKU window with the battery path proven, the motor speed the routine needs, every service CAL in range | `src/app/commission.c: start, preconditions` |
| Watch (1 ms) | the same list + the tool's heartbeat (200 ms), the locked rotor's motion (2° el), the dyno's steadiness (5 %), a current bound, no voltage saturation, the schedule; any loss: abort to the normal safe state (no service modulation, the bridge armed idle, or the §6 decision's), `DTC_MC_ABORTED` | `mc_task, watch, mc_abort` |
| No torque | the state machine does not see the VCU's enable from a start until the VCU withdraws it; an enable ends the routine and is never executed | `mc_torque_barred`; `app.c: gather` |
| R_s | 30 / 60 A DC along phase U's axis, locked rotor; ΔV/ΔI from the duties (the inverter error cancels) | `plan, mc_isr_*, est_rs` |
| L_d, L_q | 20 A sinusoidal **current** reference at f_isr/40 along d then q on a 50 A bias (no phase current crosses zero); 2 × 2 impedance from both runs, actuation delay and hold undone, eigenvalues in the frame of the zero used; AXES when the saliency axis disagrees with it | `est_ldq, ldq` |
| ψ, zero, direction | i_d = i_q = 0 on the dyno: ψ = \|e\|/\|ω_e\|, zero = the record's + atan2(e_d, e_q); the voltage vector's turn against the resolver (DIR_PHASES), the resolver against the attested dyno (DIR_DYNO) | `est_psi, emf` |
| Staging | VALID + inside the FW-20 class limits (`calib_check`'s ranges) + inside its band of the record (10 / 10 / 5 % / 2° el) ⇒ staged; beyond ⇒ a second agreeing run (3 σ) | `judge, class_ok` |
| Commit | RoutineControl 0xF021 with a fresh unlock and the bridge not switching (the record's NVM copy is a PRIMASK section): the active record + the staged values, `calib_seal` + `calib_check` (layout, CRC, ranges, SKU, UID, motor ID), a new NV_REC_CALIB version, `DTC_MC_CAL_WRITTEN`; this key cycle keeps its record, the next init validates the new one | `commit` |
| UDS | `31 01 F0 20 [routine] [attest]` start, `31 02 F0 20` stop, `31 03 F0 20 [index]` results (the heartbeat), `31 01 F0 21` commit | `mc_uds_handle` (pre-dispatched from `app.c: diag`) |
| CALs | 31 values with ranges (`mc_cal_t`), checked at every start: a bad one refuses the service mode, never driving | `MC_CAL_DEFAULT, RANGES` |
| Host plant | a virtual PMSM — L_d ≠ L_q, R_s, ψ, the true electrical zero, the resolver (reversible), a dead time differing from the FOC's compensation, the target's actuation delay, the rotor locked / dyno-driven / free | `src/platform/host/sim_pmsm.c`; `tests/harness.h: H.plant` |

**Tolerances on the host plant** (L_d 0.30 / L_q 0.55 mH, R_s 21 mΩ, ψ 0.128 Wb, the zero 20° el off the record): stated
R_s, L_d, L_q 1 %, ψ 0.5 %, the zero 3.5 mrad; achieved on the 8XX SiC set (20 kHz loop, 500 Hz injection, 750 V) R_s
+0.11 %, L_d −0.10 %, L_q −0.01 %, ψ −0.10 %, the zero +0.54 mrad (+0.03° el), on the 4XX IGBT set (10 kHz, 250 Hz,
400 V) −0.05 %, −0.13 %, −0.17 %, −0.15 %, −0.75 mrad (−0.04° el) — round 23 fix 7 (the resolver angle dated at the
demodulator's own centroid): the zero −0.50 / −1.72 mrad, the rest within 0.1 % of these. Two estimator effects the plant exposed are designed
out: the FOC's own dead-time compensation acts on a current sampled 1.5 periods earlier (at 500 Hz it read as +45 µH on
both axes: the voltage is taken from the duties), and the inverter error differs between the d and q runs unless both
share one DC operating point (−9 % saliency without the bias).

**Tests** (`tests/test_commission.c`, suite `commission`, 10 tests): the service CALs' ranges; the three routines recover
the plant on SiC and IGBT, read over UDS with their uncertainties; L_d/L_q AXES with the record's zero 20° off, VALID with
it right; confirmation (pending → a disagreeing second run replaces it → an agreeing third stages; a value inside its band
stages at once; ψ and the zero confirmed across the two dyno directions); the record written only through FW-20 after
confirmation — refused with nothing staged, without a fresh unlock or while the bridge switches, the running cycle's record untouched, the
NVM record sealed and `calib_check`-clean, the next power-up arms with it, another card refuses it; every precondition
refuses the start with its reason (unlock, routine, length, attestation, CAL, evidence, record, §6 row, DTC, VCU enable,
vehicle speed invalid / moving, V_DC below the window, the dyno not turning, a "locked" rotor turning, above the dyno
window, RUN, disarmed; the service records are not active DTCs); a running routine aborts on vehicle speed, a DTC, the
heartbeat, V_DC, a §6 row (HVIL), a VCU enable, the tool's stop, a free rotor (light: by its speed; heavy: by its angle,
within the 2° el band) and a dyno speed step — each within its bound, the modulation off, nothing staged; no torque
command accepted in service mode; the resolver direction (DIR_PHASES with sin/cos swapped, DIR_DYNO against the attested
direction); a value outside the FW-20 class never staged (and, at the default margin, the start transient of a record ψ
far from the machine's aborts with CURRENT). Counts: 10 tests, 266 checks of the suite; on the round's starting tree
300 → 310 tests, 2802 → 3068 checks, 0 failures, also with ASan/UBSan and at −O2; `make target-check` 52 → 55
markers, each with its row (this item's three `TODO(HW)`: T-51…T-53). 21 mutations of the checks, each undone once, all
caught (`docs/traceability.md`, FW-39).

**Hooks elsewhere** (minimal insertions): `app.c` — the include, `mc_init()` in `app_init`, the UDS pre-dispatch in
`diag`, the references before and the sample after `foc_step`, `mc_task` before `gather`, the enable bar in `gather`, the
service modulation in `torque_path`; `dtc.h` — `DTC_MC_ABORTED`, `DTC_MC_CAL_WRITTEN`; `can_cmd.h/.c` — the VCU's vehicle
speed (VCU_CMD b4 [5], b6–7) and `can_vcu_cmd_vspeed()`; `tests/harness.h/.c` — `H.plant`, `H.veh_speed_*`.

### FW-40 — Diagnostic services: fault history / DTC export and read-only telemetry over UDS
The data the firmware already keeps — the DTC store, the NVM fault ring (`nv_fault_t`, `nv_read_fault()`, which had no
caller) and the live state — made readable by a service tool over ISO 14229-1 on the diagnostic bus (contract §10h;
`docs/firmware-vs-vesc.md` gaps 3 and 6). Read-only for control: nothing it writes is read by a control decision (0x14
keeps the one DTC control reads, `DTC_DESAT_REPEAT`).

| Part | What it does | Where |
|---|---|---|
| 0x19 | `01` count and `02` list by status mask (AND the availability mask 0x7F), `0A` every DTC, `04` the snapshot records of a DTC — the fault ring newest first, record n = its n-th newest event, 0xFF all; two ring records per task, restarted once if a record lands meanwhile | `src/comms/uds_diag.c: read_dtc_info, scan_step` |
| DTC numbers | 0xD10000 \| the position in `dtc_id_t` (`dtc_code()`, format 0x01); name, number and description generated from `dtc.h`: JSON for the tool, the C table the unit test checks, the contract's Markdown | `tools/dtc-table.mjs` (`--c`, `--md`, `--check`), `src/comms/dtc_table.h` (generated) |
| Status byte | the bits the store tracks (TF, TFTOC, pending, confirmed, TNCSLC, TFSLC, TNCTOC), as it tracks them; warningIndicator not tracked | `src/comms/dtc.c` (unchanged but `dtc_clear`) |
| Snapshot | DID 0xFD2F, 49 bytes: the stored record — key cycle, time, row, action, speed, i_d, i_q, V_DC — and the operating context FW-40 appended to `nv_fault_t`: state, torque command and applied, hottest module NTC, the two motor sensors | `nvlog.h: nv_fault_ctx_t`; `app.c: ctx_now`; `fault_mgr.c: fm_desat` |
| 0x22 | every 0x22 reaching it (the other items' DIDs are answered before it; unknown: NRC 0x31); 12 DIDs (round 23, FW-46: a 13th, 0xFD46 the ripple table, written by 0x2E), up to 8 per request: 0xF200 state, 0xF201 arming and the FW-24 evidence item by item, 0xF202 speed and torque (command and applied, FW-37), 0xF203 currents, 0xF204 both V_DC channels, 0xF205 temperatures, 0xF206 limits in force, 0xF207 watchdog and heartbeat, 0xF208 uptime and DTC counts, 0xFD20 identity (`TI_FW_ID`), 0xFD21 calibration layout/version, 0xFD22 the validation record | `DIDS`, `did_*`; each copied between two current-loop ISRs (`did_copy`) |
| 0x2A | the 0xF2xx DIDs as a stream at 100 / 10 / 1 ms (slow / medium / fast; 1 kHz the ceiling), four at most, UUDT frames on 0x6E9; one frame per task at most, none beside a response frame, round robin; a busy mailbox drops it (counted) | `periodic_rq`, `periodic_step` |
| 0x14 | gated as the FW-32 routine: SecurityAccess (one clear per unlock), HV absent (unknown = present), the bridge disarmed; the DESAT class, the service lock and the key cycle's no-arming failures are **kept** — a clear releases no latch, so it must not hide one; the fault ring is not erased | `clear_dtcs`, `kept`; `dtc.c: dtc_clear` |
| Transport | ISO 15765-2 on CAN-FD (TX_DL 64): requests in single frames (classic or escape) — round 23 fix 11: segmented requests for the FW-38 programming services under this ECU's flow control (BS 4, STmin 0, N_Cr 1 s); responses classic / escape single frames or first + consecutive frames under the tester's BS, STmin, WAIT, overflow; N_As, N_Bs 1 s; retried while the mailbox is busy | `tp_step`, `send_usdt`, `flow_control`; `rx_first`, `rx_consecutive`, `rx_flow_control`, `rx_dispatch` |
| Wiring | one dispatch line in `uds_handle()` (after FW-41's), `uds_diag_tick()` at the end of `app.c: diag`, `app_t.udsd` | `uds.c`, `app.c`, `app.h` |

**Tests** (`tests/test_uds_diag.c`, suite `uds_diag`, 11 tests, 649 checks): every DTC has its number and description;
0x19 01/02/0A against the simulation's injected faults (HVIL open, V_DC channels apart, a DTC failed then passed) equal to
the store bit for bit for six masks; 0x19 04 after two DESATs (the FW-15 retry path) byte for byte the stored records,
records 1/2/0xFF, empty, out of range, the scan over tasks; a record written during a scan (restart; twice: NRC 0x22);
every DID against the live state at the same instant (floats bit-exact), eight DIDs in one escape request = eight single
reads; 0x14 refused without the unlock (0x33), with HV present, unknown, and armed (also armed with the link reading
20 V) (0x22), the clear and the unlock consumed; the DESAT class and the service lock kept (status, occurrences, times),
the retry still refused; 30 malformed requests with their NRCs, invalid frames unanswered, a 4000-frame fixed-seed fuzz
with every answer well-formed and the store unchanged; the flow control (STmin, BS, WAIT, a busy mailbox, N_Bs,
overflow, abort by a new request); the stream (1 kHz, round robin, rates, re-rate, stop, capacity, drops, content =
the DID); a 400-task run at 3000 rpm with four DIDs at 1 kHz bit-identical in every control output and task end time to
one without, the layer taking no simulated time. Counts: the tree as FW-40 landed 358 tests / 3792 checks, with it 369 /
4441, 0 failures, also with ASan/UBSan and at −O2 (other agents' suites in progress at the same time: see the round's final
counts). 21 mutations, each undone, all caught — the three 0x14 gates, `DTC_DESAT_REPEAT` and the service lock made
clearable, the unlock not consumed, the status mask ignored, i_d/i_q swapped, records of every DTC, no scan restart, the V_DC
channels swapped, a malformed 0x22 length accepted, every due DID in one task, periodic beside a response, block size,
STmin, N_Bs, WAIT, a busy mailbox losing the frame, the layer waiting 5 µs, the torque command not recorded
(`docs/traceability.md`, FW-40). `make target-check`: no marker added or moved by FW-40. `TI_FW_ID` unchanged (the image
and the `nv_fault_t` layout changed: the round's ID bump covers it; old ring records read ext = 0).

**Hooks elsewhere** (minimal insertions): `uds.c` — the include and one dispatch line; `app.c` — `uds_diag_tick()` in
`diag`, the operating context in `ctx_now`; `app.h` — the include (after `TI_FW_ID`, so the T-06 marker keeps its line)
and `app_t.udsd`; `dtc.h/.c` — `dtc_clear()`; `nvlog.h` — `nv_fault_ctx_t`; `fault_mgr.h/.c` — `fm_ctx_t.op` into the
DESAT record; `platform/host/sim.h`, `sim_hal.c` — `sim_can_tx_busy()` (the target's one TX mailbox busy);
`tests/test.h`, `test_main.c` — the suite.

### FW-41 — Sampled-waveform capture with fault trigger
A read-only oscilloscope-style capture (contract §10i; `docs/firmware-vs-vesc.md` gap 4): nothing in control reads it.

| Part | Implementation | Tests (`tests/test_capture.c`, suite `capture`) |
|---|---|---|
| Ring | `src/diag/capture.c/.h`: `CAP_N` = 2048 records × 32 B = 64 KiB (build-time, `-DCAP_N=…`; 12.5 % of the S32K396's 512 KB of system SRAM), one per current-loop ISR: its entry time, flags (the §6 rows, bridge mode, state, the validities, the §6 action, the trigger mark) and 12 int16 channels — i_a/i_b/i_c, i_d/i_q and their references, v_d/v_q, V_DC (0.05 A / 0.05 V), the resolver angle (2π/32768 rad) and speed (1 rpm). `cap_isr()` is the last statement of `app_isr_current()`: a bounded copy of values the ISR holds, no conversion, no wait, no loop (not a number → −32768, saturation at ±32767, the angle wrapped) | `records_every_channel_at_the_documented_scales` |
| Triggers | a new DTC occurrence (`dtc_events()`, a count added to `dtc.c`) or a new §6 row; the command; a level on one channel with hysteresis; a sources mask; the pre-/post-trigger split set with every arm (default `CAP_N`/2); frozen until re-armed; armed at every start-up | `a_fault_trigger_lands_at_the_configured_split` (splits 0, 1, 777, 2047; frozen means frozen), `an_early_trigger_keeps_only_the_records_it_has`, `the_command_trigger`, `the_level_trigger_needs_its_hysteresis`, `the_sources_mask_selects_the_triggers`, `the_ring_never_overruns_and_never_blocks` (60 random captures), `the_isr_copy_is_a_bounded_copy_on_the_host` |
| End to end | the whole firmware on the simulated card in RUN at 1000 rpm / 100 Nm, pre 1500: the fault's record at index 1500, the 160 current-loop ISRs around it equal record by record to what the ISR computed, the currents before the fault the plant's (Σi ≈ 0, on the reference's circle) | `a_desat_is_captured_at_the_split_…` (the first ISR after the fault ISR), `an_overcurrent_…` (the first sample beyond 601 A), `an_overvoltage_…` (the first ISR after the ADC-watchdog fault), `a_resolver_loss_…` (the first tick at which the newest frame is `cal_rslv_hold_us` old) |
| Read-out | `src/diag/uds_capture.c/.h`, called first in `uds_handle()` (one dispatcher line): `22 FD 40` status, `22 FD 41` the next 56-byte block with its number and the capture id, `2E FD 41` seek, `31 01 F0 41` (re-)arm with an optional configuration (a CAN-FD single frame), `31 01 F0 42` trigger; a response over 7 bytes is a CAN-FD single frame. FW-40's DID table can call `cap_status()` / `cap_image_read()` / `cap_arm()` / `cap_trigger()` instead | `uds_read_out_sequence_integrity_and_rearm`, `the_capture_reads_out_over_the_diagnostic_bus_while_the_inverter_runs` (1176 blocks through the 1 ms task under torque; the ISR grid and the frozen capture unchanged) |
| Decoder | `tools/capture-decode.mjs` (Node, no dependencies): the blocks (hex lines, any order) → CSV; refuses a missing block, two captures, a conflicting repeat, an image its header does not account for | `the_blocks_decode_to_the_waveform_through_the_node_decoder` (the C test writes the blocks, runs the decoder, reads its CSV back; three refusals) |

Cost (`docs/timing.md`): 12–15 ns per call on the host reference; ≈ 300 Thumb-2 instructions on the M7's common path, ≤ 1 µs at
320 MHz estimated (≤ 4 % of the budget at 20 kHz); on silicon: checklist T-43. The existing timing assertions (the FW-06 15.6 µs
chain, the FS26 cadence, FW-31 liveness, the ASC-exit edge, FW-34's read delays) pass with the capture armed from boot in every
scenario. Twelve mutations — the split off by one, no hysteresis, a row's level taken for its edge, writing while frozen, a
read-out with an arm pending, the cursor kept across captures, the id not advanced, a non-number recorded as a value, every
`dtc_set` counted, the angle saturated instead of wrapped, a command surviving a re-arm, an arm without its configuration — and
the hook removed from the ISR: each caught (2 to 62 failed checks). Suite: 15 tests, 180 checks, in the host, −O2 and
ASan/UBSan builds. `TI_FW_ID` unchanged.
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

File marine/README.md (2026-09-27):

# Marine Series — propulsion inverter cells (M8 · M10)

A **separate product series** from the Road GEN-1 traction inverter. It has its own product
codes, ratings, firmware build, enclosure, type approval and change control. It shares the
Road design's supply chain, verification method and, for M8, a frozen fork of its PCBs.
Status 2026-09-23: **definition and verified sizing — no marine hardware is built.**

- Engineering basis, sources and decisions: [`design-basis.md`](design-basis.md)
- Every number below: [`verification-report.md`](verification-report.md), generated by
  `npm run marine` (**86 PASS · 22 WARN · 0 FAIL**; each WARN names a vendor, class or bench gate)

## The idea in one paragraph

A marine propulsion drive is sized by **continuous** current, not a 30 s peak. It must
reduce power instead of tripping, and it must survive a single failure. So the product is a
**3-phase cell** (≈150–250 kW continuous), and power is built up from **cells per motor**.
A MW-class PM propulsion motor is built as **N separate 3-phase winding sets**
(6/9/12-phase = dual/triple/quad), and each set is fed by its own cell. Danfoss (DUAL/QUAD
EM-PMI) and The Switch (dual-winding MW machines) already sell such motors. Losing a cell
costs 1/N of the torque, not the ship. "Low RPM, high torque" is the motor's job. The inverter
sees an ordinary 40–80 Hz output, because low-speed PM motors have many poles.

## The range

| Cell | Silicon (hiitio, D3 footprint) | DC bus | Continuous (ferry duty) | Tug duty* | Built as |
|---|---|---|---|---|---|
| **M8** | HCG600FH120D3E1EA 1200 V/600 A IGBT, 5 kHz | 500–850 V | **300 A → 214 kW** @720 V | 220 A → 157 kW | frozen fork of the Road 8XX IGBT boards + marine kit |
| **M8-SiC** | HCS600FH120D3C1 1200 V SiC, 10 kHz | 500–850 V | 300 A → 214 kW, 98.9 % at cruise | 235 A → 167 kW | fork of Road 8XX SiC; small craft, short cables, on request |
| **M10** | HCG600FH170D3E1 / E1A 1700 V/600 A IGBT, 3 kHz | 650–1100 V | **270 A → 254 kW** @950 V | 190 A → 179 kW | new 1100 V power stage, Road control card |
| M10-2P | 2 × 1700 V/600 A per switch | 650–1100 V | 495 A → 465 kW | 350 A → 329 kW | new 6-module power PCB — built for a 60–70 t tug order |

Rating basis:

- 45 °C coolant.
- Tj ≤ 125 °C continuous, with a 110 % / 60 s overload.
- Life ≥ 2 × a 20-year mission (LESIT model).

\*Tug duty assumes 6 jobs × 20 full-power pulses per day. The pulse count is an estimate: an
owner's measured profile moves this rating, not the hardware.

**Why IGBT for marine, and when SiC.**
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

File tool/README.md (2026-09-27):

# Traction Tool — simulator bridge and protocol exports

The language-neutral core of the Traction Tool, the bench/service application for the 220 kW / 800 V traction
inverter. The desktop application itself is a Qt 6 (C++) program; this folder gives it three things:

| Path | What it is |
|---|---|
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

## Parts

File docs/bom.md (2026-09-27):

# Traction Inverter — 8XX · SiC (HCS600FH120D3C1), 500–850 V bus — BOM (rev A.23, generated 2026-09-27)

220 kW pk / 800 V SiC traction inverter — Power board + Cap-bank busbar + bolt-on Discharge board + Control card (round 23, A20-F05: the intro follows the SKU; it read "220 kW pk / 800 V SiC" under every variant heading before).
Generated from the built netlists by `calculations/bom-gen.mjs`; the sheets, the BOM and the
LCSC fields resolve parts through the same parts-db, so they cannot disagree.
Prices are INR planning figures at ~1k-inverter aggregate (RFQ ±30 %); hiitio module and
LEM sensor prices are quote-gated — figures below are the planning assumptions.
`CLASS` = buy to the rating printed on the sheet; `ALT` = footprint-compatible second source.
Same PCBs for every SKU — this BOM differs from the others only in the rows listed in `parts-db.mjs` SKUS.sic8.
All SKUs: [8XX SiC](bom.md) · [8XX IGBT](bom-igbt.md) · [4XX IGBT](bom-igbt4.md) · [4XX SiC](bom-sic4.md) — comparison in [`variants.md`](variants.md).

## power — 324 components, 97 BOM lines, ≈ ₹60,381 @1k

CSV: [`docs/bom-power.csv`](bom-power.csv). Top cost lines:

| Qty | MPN | Description | ₹ ext @1k | Alt |
|---|---|---|---|---|
| 3 | HCS600FH120D3C1 | SiC MOSFET half-bridge module 1200 V 600 A, hiitio D3 outlin | 54,000 | pin-map-verified hiitio drop-ins only: H |
| 6 | VGT12EEM-200S1A4 | gate-drive flyback transformer EE, AEC-Q200, 2.6 kVrms — Dig | 2,100 | Wurth 750318131 class / CN custom-wound  |
| 2 | UCC12051QDVERQ1 | AEC-Q100 iso 5 V -> 5.0 V 500 mW DC/DC, SOIC-16W | 980 | PRODUCTION: UCC12051QDVERQ1 (AEC-Q100 G1 |
| 3 | FILM-1uF-1200V | 1 uF 1200 V film snubber at module DC terminals | 540 | B32774D0505K000 5 uF C3809992 (retune) / |
| 6 | NSI6611ASC-Q1SWR | iso gate driver 10 A | 510 | NSI6602B / UCC21750-Q1 (map differs) |
| 1 | UCC14141QDWNRQ1 | reinforced isolated bias, 8-18 V in, single-output configura | 450 | UCC14240QDWNRQ1 (24 V-in bin, same pins) |
| 1 | IPL1-120-01-L-D-K | 40-way | 245 | TE AMPMODU Mod II 6-102618-8 header / 3- |
| 2 | AMC1311BDWVR | iso voltage amp 0-2 V in, reinforced | 230 | NSI1311 class |
| 1 | VOW3120-X017T | opto buffer: latched ASC_CMD -> LS driver ASC pins | 190 | Broadcom HCNW3120-500E (widebody, V_IORM |
| 5 | STUD-M8 | HV DC entry M8 stud | 140 | M10 |
| 1 | TPS55340QRTERQ1 | boost 12->15.0 V | 140 | LM5155-Q1 (controller — a redesign, not  |
| 1 | IPL1-104-01-L-S-K | discharge-board control link | 125 | IPL1-104-01-L-S-RA-K (right angle) |

## capbank — 26 components, 4 BOM lines, ≈ ₹4,940 @1k

CSV: [`docs/bom-capbank.csv`](bom-capbank.csv). Top cost lines:

| Qty | MPN | Description | ₹ ext @1k | Alt |
|---|---|---|---|---|
| 16 | C3D1M206KFSA382 | DC-link film 20 uF 1100 V p37.5 | 4,800 | TDK B32778G0406K000 40 uF 4-lead (1 per  |
| 2 | STUD-M8 | cap-bank busbar HV entry lug | 56 | M10 |
| 6 | TAB-M6 | cap-bank busbar DC tab onto EconoDUAL module terminal | 48 | per busbar drawing |
| 2 | STUD-M6 | cap-bank busbar stud for the bolt-on discharge board | 36 | M8 |

## discharge — 35 components, 17 BOM lines, ≈ ₹1,307 @1k

CSV: [`docs/bom-discharge.csv`](bom-discharge.csv). Top cost lines:

| Qty | MPN | Description | ₹ ext @1k | Alt |
|---|---|---|---|---|
| 1 | UCC14141QDWNRQ1 | reinforced isolated bias, 8-18 V in, single-output configura | 450 | UCC14240QDWNRQ1 (24 V-in bin, same pins) |
| 1 | HCM75S12T4K3 | SiC MOSFET 1200 V 75 mR TO-247-4L | 350 | 1200 V >=5 A SiC FET in TO-247-4L with t |
| 1 | VOW3120-X017T | opto gate driver | 190 | Broadcom HCNW3120-500E (widebody, V_IORM |
| 1 | IPL1-104-01-L-S-K | discharge-board control link | 125 | IPL1-104-01-L-S-RA-K (right angle) |
| 4 | SQP10-470RJB15 | TT/Welwyn SQP statement: 'will not burn or emit incandescent | 112 | Yageo SQP10AJB-470R only with the same n |
| 2 | STUD-M6 | discharge-board bolt terminal onto the cap bank / busbar | 36 | M8 |
| 12 | R2512-22k-2W | 22 k 2512 2 W standard thick-film | 36 | TE CRGP2512F68K C2073426 (101 pcs LCSC)  |
| 2 | MLCC-10uF-25V-X7R | UCC14141-Q1 VIN bulk 2 x 10 uF | 3 | any X7R 25 V |
| 1 | MLCC-10uF-50V | UCC14141-Q1 COUT1 10 uF at VDD-VEE | 2 | any X7R 50 V |
| 2 | MLCC-100nF-50V | UCC14141-Q1 VIN high-frequency bypass, at pins 6/7-8 | 1 | any |
| 2 | R0603-10k | UCC14141-Q1 ENA divider top from V15 | 1 | any |
| 1 | R0603-62k-1% | UCC14141-Q1 FBVDD divider top: 2.5 V x | 0 | any 1 % |

## control-card — 304 components, 120 BOM lines, ≈ ₹6,355 @1k

CSV: [`docs/bom-control-card.csv`](bom-control-card.csv). Top cost lines:

| Qty | MPN | Description | ₹ ext @1k | Alt |
|---|---|---|---|---|
| 3 | HC5FW900-S | open-loop hall 900 A busbar transducer, 5 V ratiometric | 2,100 | HAH1BVW S/08 900 A class (LEM) |
| 1 | S32K396EHT1MJBST | lockstep M7 motor-control MCU | 1,400 | S32K388 (same family, different ball map |
| 1 | TE 770669-1 (AMPSEAL 23) | 23-pos AMPSEAL PCB header, right-angle shrouded | 780 | 1-770669-x plating variants / Aptiv GT 2 |
| 1 | FS2633D | ASIL-D SBC: VPRE 5.4V buck / VCORE 1.5V buck / VREF 5V / LDO | 480 | FS2630 variants |
| 9 | OPA376AQDBVRQ1 | VDC differential receiver | 252 | OPA320-Q1 |
| 1 | IPL1-120-01-L-D-K | 40-way | 245 | TE AMPMODU Mod II 6-102618-8 / 2-826634- |
| 1 | ALM2402QPWPRQ1 | dual power op-amp resolver driver, 8 Vpp H-bridge out | 180 | ALM2403QPWPRQ1 (DigiKey ships-today) |
| 2 | TCAN1042HGVDRQ1 | CAN-FD 5 Mbps transceiver, VIO, AEC-Q100 — automotive grade  | 110 | TCAN1042DRQ1 C118837 (loses 70 V fault t |
| 3 | OPA348AQDBVRQ1 | VMID buffers | 75 | OPA365-Q1 / commercial OPA348AIDBVR C363 |
| 2 | OPA333AQDBVRQ1 | zero-drift buffer, motor temp | 70 | OPA388-Q1 |
| 1 | EEH-ZC1H101P | NRC bulk 100 uF 50 V conductive-polymer hybrid aluminium, ZC | 45 | EEH-ZC1H121P (120 uF, same G case: 33.6  |
| 1 | CX3225GA40000D0PTVCC | 40 MHz crystal | 45 | NX3225GA-40M / SOSET 3225 40 MHz C538031 |

## BOM contribution by subsystem (all boards, ₹ @1k)

Where the money actually goes — cumulative share shows the Pareto: the first two rows are
~87 % of the electronics BOM, so those are the only two lines worth an RFQ fight.

| Subsystem | ₹ | share | cumulative | parts |
|---|---|---|---|---|
| SiC power modules | 54,000 | 74.0% | 74.0% | 3 |
| DC-link film caps | 4,800 | 6.6% | 80.6% | 16 |
| Hall sensors + AFE | 2,327 | 3.2% | 83.8% | 38 |
| Gate-power flybacks | 2,252 | 3.1% | 86.8% | 77 |
| MCU + clock + debug | 1,496 | 2.0% | 88.9% | 22 |
| VDC iso sensing + bias | 1,296 | 1.8% | 90.7% | 30 |
| Discharge (active+passive) | 1,146 | 1.6% | 92.2% | 33 |
| Vehicle connector + prot | 788 | 1.1% | 93.3% | 6 |
| FS26 SBC + LV input + wake | 691 | 0.9% | 94.3% | 40 |
| Gate drivers + networks | 659 | 0.9% | 95.2% | 129 |
| ASC buffer | 650 | 0.9% | 96.1% | 18 |
| misc | 604 | 0.8% | 96.9% | 59 |
| Module snubbers | 540 | 0.7% | 97.6% | 3 |
| Harness + pulldowns | 495 | 0.7% | 98.3% | 17 |
| HV entry/Y-caps/HVIL/studs | 302 | 0.4% | 98.7% | 14 |
| LV power (prot+LDO+boost) | 278 | 0.4% | 99.1% | 28 |
| Resolver AFE | 276 | 0.4% | 99.5% | 54 |
| CAN-FD x2 | 132 | 0.2% | 99.7% | 14 |
| Temps (module/board/motor) | 97 | 0.1% | 99.8% | 24 |
| Safety chain (EN/ASC/ILK) | 89 | 0.1% | 99.9% | 43 |
| VDC receivers (card) | 61 | 0.1% | 100.0% | 12 |
| Module NTC routing | 4 | 0.0% | 100.0% | 9 |

## Cost by category (all boards, ₹ @1k)

| Category | ₹ | share |
|---|---|---|
| power semiconductors | 55,986 | 76.7% |
| drive + control ICs | 7,378 | 10.1% |
| capacitors | 4,980 | 6.8% |
| magnetics | 2,195 | 3.0% |
| connectors + sensors | 1,561 | 2.1% |
| misc | 427 | 0.6% |
| isolation | 231 | 0.3% |
| protection + diodes | 132 | 0.2% |
| resistors | 94 | 0.1% |
| **TOTAL (electronics, ex-PCB/mech/busbar/coldplate)** | **72,983** | 100% |

The three HCS600FH120D3C1 modules dominate (as they should at this power class); every
other line is distributor-standard. Swapping the module vendor swaps one BOM line.

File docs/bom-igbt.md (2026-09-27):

# Traction Inverter — 8XX · IGBT (HCG600FH120D3E1EA), 500–850 V bus — BOM (rev A.22, generated 2026-09-26)

220 kW pk / 800 V IGBT traction inverter (5 kHz) — Power board + Cap-bank busbar + bolt-on Discharge board + Control card (round 23, A20-F05: the intro follows the SKU; it read "220 kW pk / 800 V SiC" under every variant heading before).
Generated from the built netlists by `calculations/bom-gen.mjs`; the sheets, the BOM and the
LCSC fields resolve parts through the same parts-db, so they cannot disagree.
Prices are INR planning figures at ~1k-inverter aggregate (RFQ ±30 %); hiitio module and
LEM sensor prices are quote-gated — figures below are the planning assumptions.
`CLASS` = buy to the rating printed on the sheet; `ALT` = footprint-compatible second source.
Same PCBs for every SKU — this BOM differs from the others only in the rows listed in `parts-db.mjs` SKUS.igbt8.
All SKUs: [8XX SiC](bom.md) · [8XX IGBT](bom-igbt.md) · [4XX IGBT](bom-igbt4.md) · [4XX SiC](bom-sic4.md) — comparison in [`variants.md`](variants.md).

## power — 324 components, 99 BOM lines, ≈ ₹34,881 @1k

CSV: [`docs/bom-power-igbt.csv`](bom-power-igbt.csv). Top cost lines:

| Qty | MPN | Description | ₹ ext @1k | Alt |
|---|---|---|---|---|
| 3 | HCG600FH120D3E1EA | IGBT half-bridge module 1200 V 600 A, SAME D3 EconoDUAL 3 fo | 28,500 | - |
| 6 | VGT12EEM-200S1A4 | gate-drive flyback transformer EE, AEC-Q200, 2.6 kVrms — Dig | 2,100 | Wurth 750318131 class / CN custom-wound  |
| 2 | UCC12051QDVERQ1 | AEC-Q100 iso 5 V -> 5.0 V 500 mW DC/DC, SOIC-16W | 980 | PRODUCTION: UCC12051QDVERQ1 (AEC-Q100 G1 |
| 3 | FILM-1uF-1200V | 1 uF 1200 V film snubber at module DC terminals | 540 | B32774D0505K000 5 uF C3809992 (retune) / |
| 6 | NSI6611ASC-Q1SWR | iso gate driver 10 A | 510 | NSI6602B / UCC21750-Q1 (map differs) |
| 1 | UCC14141QDWNRQ1 | reinforced isolated bias, 8-18 V in, single-output configura | 450 | UCC14240QDWNRQ1 (24 V-in bin, same pins) |
| 1 | IPL1-120-01-L-D-K | 40-way | 245 | TE AMPMODU Mod II 6-102618-8 header / 3- |
| 2 | AMC1311BDWVR | iso voltage amp 0-2 V in, reinforced | 230 | NSI1311 class |
| 1 | VOW3120-X017T | opto buffer: latched ASC_CMD -> LS driver ASC pins | 190 | Broadcom HCNW3120-500E (widebody, V_IORM |
| 5 | STUD-M8 | HV DC entry M8 stud | 140 | M10 |
| 1 | TPS55340QRTERQ1 | boost 12->15.0 V | 140 | LM5155-Q1 (controller — a redesign, not  |
| 1 | IPL1-104-01-L-S-K | discharge-board control link | 125 | IPL1-104-01-L-S-RA-K (right angle) |

## capbank — 26 components, 4 BOM lines, ≈ ₹4,940 @1k

CSV: [`docs/bom-capbank-igbt.csv`](bom-capbank-igbt.csv). Top cost lines:

| Qty | MPN | Description | ₹ ext @1k | Alt |
|---|---|---|---|---|
| 16 | C3D1M206KFSA382 | DC-link film 20 uF 1100 V p37.5 | 4,800 | TDK B32778G0406K000 40 uF 4-lead (1 per  |
| 2 | STUD-M8 | cap-bank busbar HV entry lug | 56 | M10 |
| 6 | TAB-M6 | cap-bank busbar DC tab onto EconoDUAL module terminal | 48 | per busbar drawing |
| 2 | STUD-M6 | cap-bank busbar stud for the bolt-on discharge board | 36 | M8 |

## discharge — 35 components, 17 BOM lines, ≈ ₹1,307 @1k

CSV: [`docs/bom-discharge-igbt.csv`](bom-discharge-igbt.csv). Top cost lines:

| Qty | MPN | Description | ₹ ext @1k | Alt |
|---|---|---|---|---|
| 1 | UCC14141QDWNRQ1 | reinforced isolated bias, 8-18 V in, single-output configura | 450 | UCC14240QDWNRQ1 (24 V-in bin, same pins) |
| 1 | HCM75S12T4K3 | SiC MOSFET 1200 V 75 mR TO-247-4L | 350 | 1200 V >=5 A SiC FET in TO-247-4L with t |
| 1 | VOW3120-X017T | opto gate driver | 190 | Broadcom HCNW3120-500E (widebody, V_IORM |
| 1 | IPL1-104-01-L-S-K | discharge-board control link | 125 | IPL1-104-01-L-S-RA-K (right angle) |
| 4 | SQP10-470RJB15 | TT/Welwyn SQP statement: 'will not burn or emit incandescent | 112 | Yageo SQP10AJB-470R only with the same n |
| 2 | STUD-M6 | discharge-board bolt terminal onto the cap bank / busbar | 36 | M8 |
| 12 | R2512-22k-2W | 22 k 2512 2 W standard thick-film | 36 | TE CRGP2512F68K C2073426 (101 pcs LCSC)  |
| 2 | MLCC-10uF-25V-X7R | UCC14141-Q1 VIN bulk 2 x 10 uF | 3 | any X7R 25 V |
| 1 | MLCC-10uF-50V | UCC14141-Q1 COUT1 10 uF at VDD-VEE | 2 | any X7R 50 V |
| 2 | MLCC-100nF-50V | UCC14141-Q1 VIN high-frequency bypass, at pins 6/7-8 | 1 | any |
| 2 | R0603-10k | UCC14141-Q1 ENA divider top from V15 | 1 | any |
| 1 | R0603-62k-1% | UCC14141-Q1 FBVDD divider top: 2.5 V x | 0 | any 1 % |

## control-card — 304 components, 119 BOM lines, ≈ ₹6,355 @1k

CSV: [`docs/bom-control-card-igbt.csv`](bom-control-card-igbt.csv). Top cost lines:

| Qty | MPN | Description | ₹ ext @1k | Alt |
|---|---|---|---|---|
| 3 | HC5FW900-S | open-loop hall 900 A busbar transducer, 5 V ratiometric | 2,100 | HAH1BVW S/08 900 A class (LEM) |
| 1 | S32K396EHT1MJBST | lockstep M7 motor-control MCU | 1,400 | S32K388 (same family, different ball map |
| 1 | TE 770669-1 (AMPSEAL 23) | 23-pos AMPSEAL PCB header, right-angle shrouded | 780 | 1-770669-x plating variants / Aptiv GT 2 |
| 1 | FS2633D | ASIL-D SBC: VPRE 5.4V buck / VCORE 1.5V buck / VREF 5V / LDO | 480 | FS2630 variants |
| 9 | OPA376AQDBVRQ1 | VDC differential receiver | 252 | OPA320-Q1 |
| 1 | IPL1-120-01-L-D-K | 40-way | 245 | TE AMPMODU Mod II 6-102618-8 / 2-826634- |
| 1 | ALM2402QPWPRQ1 | dual power op-amp resolver driver, 8 Vpp H-bridge out | 180 | ALM2403QPWPRQ1 (DigiKey ships-today) |
| 2 | TCAN1042HGVDRQ1 | CAN-FD 5 Mbps transceiver, VIO, AEC-Q100 — automotive grade  | 110 | TCAN1042DRQ1 C118837 (loses 70 V fault t |
| 3 | OPA348AQDBVRQ1 | VMID buffers | 75 | OPA365-Q1 / commercial OPA348AIDBVR C363 |
| 2 | OPA333AQDBVRQ1 | zero-drift buffer, motor temp | 70 | OPA388-Q1 |
| 1 | EEH-ZC1H101P | NRC bulk 100 uF 50 V conductive-polymer hybrid aluminium, ZC | 45 | EEH-ZC1H121P (120 uF, same G case: 33.6  |
| 1 | CX3225GA40000D0PTVCC | 40 MHz crystal | 45 | NX3225GA-40M / SOSET 3225 40 MHz C538031 |

## BOM contribution by subsystem (all boards, ₹ @1k)

Where the money actually goes — cumulative share shows the Pareto: the first two rows are
~87 % of the electronics BOM, so those are the only two lines worth an RFQ fight.

| Subsystem | ₹ | share | cumulative | parts |
|---|---|---|---|---|
| SiC power modules | 28,500 | 60.0% | 60.0% | 3 |
| DC-link film caps | 4,800 | 10.1% | 70.1% | 16 |
| Hall sensors + AFE | 2,327 | 4.9% | 75.0% | 38 |
| Gate-power flybacks | 2,252 | 4.7% | 79.8% | 77 |
| MCU + clock + debug | 1,496 | 3.1% | 82.9% | 22 |
| VDC iso sensing + bias | 1,296 | 2.7% | 85.7% | 30 |
| Discharge (active+passive) | 1,146 | 2.4% | 88.1% | 33 |
| Vehicle connector + prot | 788 | 1.7% | 89.7% | 6 |
| FS26 SBC + LV input + wake | 691 | 1.5% | 91.2% | 40 |
| Gate drivers + networks | 659 | 1.4% | 92.6% | 129 |
| ASC buffer | 650 | 1.4% | 93.9% | 18 |
| misc | 604 | 1.3% | 95.2% | 59 |
| Module snubbers | 540 | 1.1% | 96.3% | 3 |
| Harness + pulldowns | 495 | 1.0% | 97.4% | 17 |
| HV entry/Y-caps/HVIL/studs | 302 | 0.6% | 98.0% | 14 |
| LV power (prot+LDO+boost) | 278 | 0.6% | 98.6% | 28 |
| Resolver AFE | 276 | 0.6% | 99.2% | 54 |
| CAN-FD x2 | 132 | 0.3% | 99.5% | 14 |
| Temps (module/board/motor) | 97 | 0.2% | 99.7% | 24 |
| Safety chain (EN/ASC/ILK) | 89 | 0.2% | 99.9% | 43 |
| VDC receivers (card) | 61 | 0.1% | 100.0% | 12 |
| Module NTC routing | 4 | 0.0% | 100.0% | 9 |

## Cost by category (all boards, ₹ @1k)

| Category | ₹ | share |
|---|---|---|
| power semiconductors | 30,484 | 64.2% |
| drive + control ICs | 7,423 | 15.6% |
| capacitors | 4,981 | 10.5% |
| magnetics | 2,195 | 4.6% |
| connectors + sensors | 1,561 | 3.3% |
| misc | 433 | 0.9% |
| isolation | 231 | 0.5% |
| protection + diodes | 132 | 0.3% |
| resistors | 44 | 0.1% |
| **TOTAL (electronics, ex-PCB/mech/busbar/coldplate)** | **47,483** | 100% |

The three HCS600FH120D3C1 modules dominate (as they should at this power class); every
other line is distributor-standard. Swapping the module vendor swaps one BOM line.

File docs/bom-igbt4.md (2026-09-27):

# Traction Inverter — 4XX · IGBT (HCG600FH120D3E1EA), 250–500 V bus — BOM (rev A.22, generated 2026-09-26)

150 kW pk / 400 V IGBT traction inverter — Power board + Cap-bank busbar + bolt-on Discharge board + Control card (round 23, A20-F05: the intro follows the SKU; it read "220 kW pk / 800 V SiC" under every variant heading before).
Generated from the built netlists by `calculations/bom-gen.mjs`; the sheets, the BOM and the
LCSC fields resolve parts through the same parts-db, so they cannot disagree.
Prices are INR planning figures at ~1k-inverter aggregate (RFQ ±30 %); hiitio module and
LEM sensor prices are quote-gated — figures below are the planning assumptions.
`CLASS` = buy to the rating printed on the sheet; `ALT` = footprint-compatible second source.
Same PCBs for every SKU — this BOM differs from the others only in the rows listed in `parts-db.mjs` SKUS.igbt4.
All SKUs: [8XX SiC](bom.md) · [8XX IGBT](bom-igbt.md) · [4XX IGBT](bom-igbt4.md) · [4XX SiC](bom-sic4.md) — comparison in [`variants.md`](variants.md).

## power — 324 components, 99 BOM lines, ≈ ₹34,881 @1k

CSV: [`docs/bom-power-igbt4.csv`](bom-power-igbt4.csv). Top cost lines:

| Qty | MPN | Description | ₹ ext @1k | Alt |
|---|---|---|---|---|
| 3 | HCG600FH120D3E1EA | IGBT half-bridge module 1200 V 600 A, SAME D3 EconoDUAL 3 fo | 28,500 | - |
| 6 | VGT12EEM-200S1A4 | gate-drive flyback transformer EE, AEC-Q200, 2.6 kVrms — Dig | 2,100 | Wurth 750318131 class / CN custom-wound  |
| 2 | UCC12051QDVERQ1 | AEC-Q100 iso 5 V -> 5.0 V 500 mW DC/DC, SOIC-16W | 980 | PRODUCTION: UCC12051QDVERQ1 (AEC-Q100 G1 |
| 3 | FILM-1uF-1200V | 1 uF 1200 V film snubber at module DC terminals | 540 | B32774D0505K000 5 uF C3809992 (retune) / |
| 6 | NSI6611ASC-Q1SWR | iso gate driver 10 A | 510 | NSI6602B / UCC21750-Q1 (map differs) |
| 1 | UCC14141QDWNRQ1 | reinforced isolated bias, 8-18 V in, single-output configura | 450 | UCC14240QDWNRQ1 (24 V-in bin, same pins) |
| 1 | IPL1-120-01-L-D-K | 40-way | 245 | TE AMPMODU Mod II 6-102618-8 header / 3- |
| 2 | AMC1311BDWVR | iso voltage amp 0-2 V in, reinforced | 230 | NSI1311 class |
| 1 | VOW3120-X017T | opto buffer: latched ASC_CMD -> LS driver ASC pins | 190 | Broadcom HCNW3120-500E (widebody, V_IORM |
| 5 | STUD-M8 | HV DC entry M8 stud | 140 | M10 |
| 1 | TPS55340QRTERQ1 | boost 12->15.0 V | 140 | LM5155-Q1 (controller — a redesign, not  |
| 1 | IPL1-104-01-L-S-K | discharge-board control link | 125 | IPL1-104-01-L-S-RA-K (right angle) |

## capbank — 26 components, 4 BOM lines, ≈ ₹3,340 @1k

CSV: [`docs/bom-capbank-igbt4.csv`](bom-capbank-igbt4.csv). Top cost lines:

| Qty | MPN | Description | ₹ ext @1k | Alt |
|---|---|---|---|---|
| 16 | C3D1U506KFAA382 | DC-link film 50 uF 600 V | 3,200 | Vishay MKP1848C65060JP5 (verified, talle |
| 2 | STUD-M8 | cap-bank busbar HV entry lug | 56 | M10 |
| 6 | TAB-M6 | cap-bank busbar DC tab onto EconoDUAL module terminal | 48 | per busbar drawing |
| 2 | STUD-M6 | cap-bank busbar stud for the bolt-on discharge board | 36 | M8 |

## discharge — 35 components, 17 BOM lines, ≈ ₹1,307 @1k

CSV: [`docs/bom-discharge-igbt4.csv`](bom-discharge-igbt4.csv). Top cost lines:

| Qty | MPN | Description | ₹ ext @1k | Alt |
|---|---|---|---|---|
| 1 | UCC14141QDWNRQ1 | reinforced isolated bias, 8-18 V in, single-output configura | 450 | UCC14240QDWNRQ1 (24 V-in bin, same pins) |
| 1 | HCM75S12T4K3 | SiC MOSFET 1200 V 75 mR TO-247-4L | 350 | 1200 V >=5 A SiC FET in TO-247-4L with t |
| 1 | VOW3120-X017T | opto gate driver | 190 | Broadcom HCNW3120-500E (widebody, V_IORM |
| 1 | IPL1-104-01-L-S-K | discharge-board control link | 125 | IPL1-104-01-L-S-RA-K (right angle) |
| 4 | SQP10-220RJB15 | TT/Welwyn SQP statement: 'will not burn or emit incandescent | 112 | Yageo SQP10AJB-220R only with the same n |
| 2 | STUD-M6 | discharge-board bolt terminal onto the cap bank / busbar | 36 | M8 |
| 12 | R2512-15k-2W | 15 k 2512 2 W thick film | 36 | - |
| 2 | MLCC-10uF-25V-X7R | UCC14141-Q1 VIN bulk 2 x 10 uF | 3 | any X7R 25 V |
| 1 | MLCC-10uF-50V | UCC14141-Q1 COUT1 10 uF at VDD-VEE | 2 | any X7R 50 V |
| 2 | MLCC-100nF-50V | UCC14141-Q1 VIN high-frequency bypass, at pins 6/7-8 | 1 | any |
| 2 | R0603-10k | UCC14141-Q1 ENA divider top from V15 | 1 | any |
| 1 | R0603-62k-1% | UCC14141-Q1 FBVDD divider top: 2.5 V x | 0 | any 1 % |

## control-card — 304 components, 119 BOM lines, ≈ ₹6,355 @1k

CSV: [`docs/bom-control-card-igbt4.csv`](bom-control-card-igbt4.csv). Top cost lines:

| Qty | MPN | Description | ₹ ext @1k | Alt |
|---|---|---|---|---|
| 3 | HC5FW900-S | open-loop hall 900 A busbar transducer, 5 V ratiometric | 2,100 | HAH1BVW S/08 900 A class (LEM) |
| 1 | S32K396EHT1MJBST | lockstep M7 motor-control MCU | 1,400 | S32K388 (same family, different ball map |
| 1 | TE 770669-1 (AMPSEAL 23) | 23-pos AMPSEAL PCB header, right-angle shrouded | 780 | 1-770669-x plating variants / Aptiv GT 2 |
| 1 | FS2633D | ASIL-D SBC: VPRE 5.4V buck / VCORE 1.5V buck / VREF 5V / LDO | 480 | FS2630 variants |
| 9 | OPA376AQDBVRQ1 | VDC differential receiver | 252 | OPA320-Q1 |
| 1 | IPL1-120-01-L-D-K | 40-way | 245 | TE AMPMODU Mod II 6-102618-8 / 2-826634- |
| 1 | ALM2402QPWPRQ1 | dual power op-amp resolver driver, 8 Vpp H-bridge out | 180 | ALM2403QPWPRQ1 (DigiKey ships-today) |
| 2 | TCAN1042HGVDRQ1 | CAN-FD 5 Mbps transceiver, VIO, AEC-Q100 — automotive grade  | 110 | TCAN1042DRQ1 C118837 (loses 70 V fault t |
| 3 | OPA348AQDBVRQ1 | VMID buffers | 75 | OPA365-Q1 / commercial OPA348AIDBVR C363 |
| 2 | OPA333AQDBVRQ1 | zero-drift buffer, motor temp | 70 | OPA388-Q1 |
| 1 | EEH-ZC1H101P | NRC bulk 100 uF 50 V conductive-polymer hybrid aluminium, ZC | 45 | EEH-ZC1H121P (120 uF, same G case: 33.6  |
| 1 | CX3225GA40000D0PTVCC | 40 MHz crystal | 45 | NX3225GA-40M / SOSET 3225 40 MHz C538031 |

## BOM contribution by subsystem (all boards, ₹ @1k)

Where the money actually goes — cumulative share shows the Pareto: the first two rows are
~87 % of the electronics BOM, so those are the only two lines worth an RFQ fight.

| Subsystem | ₹ | share | cumulative | parts |
|---|---|---|---|---|
| SiC power modules | 28,500 | 62.1% | 62.1% | 3 |
| DC-link film caps | 3,200 | 7.0% | 69.1% | 16 |
| Hall sensors + AFE | 2,327 | 5.1% | 74.2% | 38 |
| Gate-power flybacks | 2,252 | 4.9% | 79.1% | 77 |
| MCU + clock + debug | 1,496 | 3.3% | 82.3% | 22 |
| VDC iso sensing + bias | 1,296 | 2.8% | 85.2% | 30 |
| Discharge (active+passive) | 1,146 | 2.5% | 87.7% | 33 |
| Vehicle connector + prot | 788 | 1.7% | 89.4% | 6 |
| FS26 SBC + LV input + wake | 691 | 1.5% | 90.9% | 40 |
| Gate drivers + networks | 659 | 1.4% | 92.3% | 129 |
| ASC buffer | 650 | 1.4% | 93.7% | 18 |
| misc | 604 | 1.3% | 95.0% | 59 |
| Module snubbers | 540 | 1.2% | 96.2% | 3 |
| Harness + pulldowns | 495 | 1.1% | 97.3% | 17 |
| HV entry/Y-caps/HVIL/studs | 302 | 0.7% | 98.0% | 14 |
| LV power (prot+LDO+boost) | 278 | 0.6% | 98.6% | 28 |
| Resolver AFE | 276 | 0.6% | 99.2% | 54 |
| CAN-FD x2 | 132 | 0.3% | 99.5% | 14 |
| Temps (module/board/motor) | 97 | 0.2% | 99.7% | 24 |
| Safety chain (EN/ASC/ILK) | 89 | 0.2% | 99.9% | 43 |
| VDC receivers (card) | 61 | 0.1% | 100.0% | 12 |
| Module NTC routing | 4 | 0.0% | 100.0% | 9 |

## Cost by category (all boards, ₹ @1k)

| Category | ₹ | share |
|---|---|---|
| power semiconductors | 30,484 | 66.4% |
| drive + control ICs | 10,587 | 23.1% |
| magnetics | 2,195 | 4.8% |
| connectors + sensors | 1,561 | 3.4% |
| misc | 433 | 0.9% |
| isolation | 231 | 0.5% |
| capacitors | 217 | 0.5% |
| protection + diodes | 132 | 0.3% |
| resistors | 44 | 0.1% |
| **TOTAL (electronics, ex-PCB/mech/busbar/coldplate)** | **45,883** | 100% |

The three HCS600FH120D3C1 modules dominate (as they should at this power class); every
other line is distributor-standard. Swapping the module vendor swaps one BOM line.

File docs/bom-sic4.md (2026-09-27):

# Traction Inverter — 4XX · SiC (HCS600FH120D3C1), 250–500 V bus — BOM (rev A.22, generated 2026-09-26)

150 kW pk / 400 V SiC traction inverter (on request) — Power board + Cap-bank busbar + bolt-on Discharge board + Control card (round 23, A20-F05: the intro follows the SKU; it read "220 kW pk / 800 V SiC" under every variant heading before).
Generated from the built netlists by `calculations/bom-gen.mjs`; the sheets, the BOM and the
LCSC fields resolve parts through the same parts-db, so they cannot disagree.
Prices are INR planning figures at ~1k-inverter aggregate (RFQ ±30 %); hiitio module and
LEM sensor prices are quote-gated — figures below are the planning assumptions.
`CLASS` = buy to the rating printed on the sheet; `ALT` = footprint-compatible second source.
Same PCBs for every SKU — this BOM differs from the others only in the rows listed in `parts-db.mjs` SKUS.sic4.
All SKUs: [8XX SiC](bom.md) · [8XX IGBT](bom-igbt.md) · [4XX IGBT](bom-igbt4.md) · [4XX SiC](bom-sic4.md) — comparison in [`variants.md`](variants.md).

## power — 324 components, 98 BOM lines, ≈ ₹60,381 @1k

CSV: [`docs/bom-power-sic4.csv`](bom-power-sic4.csv). Top cost lines:

| Qty | MPN | Description | ₹ ext @1k | Alt |
|---|---|---|---|---|
| 3 | HCS600FH120D3C1 | SiC MOSFET half-bridge module 1200 V 600 A, hiitio D3 outlin | 54,000 | pin-map-verified hiitio drop-ins only: H |
| 6 | VGT12EEM-200S1A4 | gate-drive flyback transformer EE, AEC-Q200, 2.6 kVrms — Dig | 2,100 | Wurth 750318131 class / CN custom-wound  |
| 2 | UCC12051QDVERQ1 | AEC-Q100 iso 5 V -> 5.0 V 500 mW DC/DC, SOIC-16W | 980 | PRODUCTION: UCC12051QDVERQ1 (AEC-Q100 G1 |
| 3 | FILM-1uF-1200V | 1 uF 1200 V film snubber at module DC terminals | 540 | B32774D0505K000 5 uF C3809992 (retune) / |
| 6 | NSI6611ASC-Q1SWR | iso gate driver 10 A | 510 | NSI6602B / UCC21750-Q1 (map differs) |
| 1 | UCC14141QDWNRQ1 | reinforced isolated bias, 8-18 V in, single-output configura | 450 | UCC14240QDWNRQ1 (24 V-in bin, same pins) |
| 1 | IPL1-120-01-L-D-K | 40-way | 245 | TE AMPMODU Mod II 6-102618-8 header / 3- |
| 2 | AMC1311BDWVR | iso voltage amp 0-2 V in, reinforced | 230 | NSI1311 class |
| 1 | VOW3120-X017T | opto buffer: latched ASC_CMD -> LS driver ASC pins | 190 | Broadcom HCNW3120-500E (widebody, V_IORM |
| 5 | STUD-M8 | HV DC entry M8 stud | 140 | M10 |
| 1 | TPS55340QRTERQ1 | boost 12->15.0 V | 140 | LM5155-Q1 (controller — a redesign, not  |
| 1 | IPL1-104-01-L-S-K | discharge-board control link | 125 | IPL1-104-01-L-S-RA-K (right angle) |

## capbank — 26 components, 4 BOM lines, ≈ ₹3,340 @1k

CSV: [`docs/bom-capbank-sic4.csv`](bom-capbank-sic4.csv). Top cost lines:

| Qty | MPN | Description | ₹ ext @1k | Alt |
|---|---|---|---|---|
| 16 | C3D1U506KFAA382 | DC-link film 50 uF 600 V | 3,200 | Vishay MKP1848C65060JP5 (verified, talle |
| 2 | STUD-M8 | cap-bank busbar HV entry lug | 56 | M10 |
| 6 | TAB-M6 | cap-bank busbar DC tab onto EconoDUAL module terminal | 48 | per busbar drawing |
| 2 | STUD-M6 | cap-bank busbar stud for the bolt-on discharge board | 36 | M8 |

## discharge — 35 components, 17 BOM lines, ≈ ₹1,307 @1k

CSV: [`docs/bom-discharge-sic4.csv`](bom-discharge-sic4.csv). Top cost lines:

| Qty | MPN | Description | ₹ ext @1k | Alt |
|---|---|---|---|---|
| 1 | UCC14141QDWNRQ1 | reinforced isolated bias, 8-18 V in, single-output configura | 450 | UCC14240QDWNRQ1 (24 V-in bin, same pins) |
| 1 | HCM75S12T4K3 | SiC MOSFET 1200 V 75 mR TO-247-4L | 350 | 1200 V >=5 A SiC FET in TO-247-4L with t |
| 1 | VOW3120-X017T | opto gate driver | 190 | Broadcom HCNW3120-500E (widebody, V_IORM |
| 1 | IPL1-104-01-L-S-K | discharge-board control link | 125 | IPL1-104-01-L-S-RA-K (right angle) |
| 4 | SQP10-220RJB15 | TT/Welwyn SQP statement: 'will not burn or emit incandescent | 112 | Yageo SQP10AJB-220R only with the same n |
| 2 | STUD-M6 | discharge-board bolt terminal onto the cap bank / busbar | 36 | M8 |
| 12 | R2512-15k-2W | 15 k 2512 2 W thick film | 36 | - |
| 2 | MLCC-10uF-25V-X7R | UCC14141-Q1 VIN bulk 2 x 10 uF | 3 | any X7R 25 V |
| 1 | MLCC-10uF-50V | UCC14141-Q1 COUT1 10 uF at VDD-VEE | 2 | any X7R 50 V |
| 2 | MLCC-100nF-50V | UCC14141-Q1 VIN high-frequency bypass, at pins 6/7-8 | 1 | any |
| 2 | R0603-10k | UCC14141-Q1 ENA divider top from V15 | 1 | any |
| 1 | R0603-62k-1% | UCC14141-Q1 FBVDD divider top: 2.5 V x | 0 | any 1 % |

## control-card — 304 components, 119 BOM lines, ≈ ₹6,355 @1k

CSV: [`docs/bom-control-card-sic4.csv`](bom-control-card-sic4.csv). Top cost lines:

| Qty | MPN | Description | ₹ ext @1k | Alt |
|---|---|---|---|---|
| 3 | HC5FW900-S | open-loop hall 900 A busbar transducer, 5 V ratiometric | 2,100 | HAH1BVW S/08 900 A class (LEM) |
| 1 | S32K396EHT1MJBST | lockstep M7 motor-control MCU | 1,400 | S32K388 (same family, different ball map |
| 1 | TE 770669-1 (AMPSEAL 23) | 23-pos AMPSEAL PCB header, right-angle shrouded | 780 | 1-770669-x plating variants / Aptiv GT 2 |
| 1 | FS2633D | ASIL-D SBC: VPRE 5.4V buck / VCORE 1.5V buck / VREF 5V / LDO | 480 | FS2630 variants |
| 9 | OPA376AQDBVRQ1 | VDC differential receiver | 252 | OPA320-Q1 |
| 1 | IPL1-120-01-L-D-K | 40-way | 245 | TE AMPMODU Mod II 6-102618-8 / 2-826634- |
| 1 | ALM2402QPWPRQ1 | dual power op-amp resolver driver, 8 Vpp H-bridge out | 180 | ALM2403QPWPRQ1 (DigiKey ships-today) |
| 2 | TCAN1042HGVDRQ1 | CAN-FD 5 Mbps transceiver, VIO, AEC-Q100 — automotive grade  | 110 | TCAN1042DRQ1 C118837 (loses 70 V fault t |
| 3 | OPA348AQDBVRQ1 | VMID buffers | 75 | OPA365-Q1 / commercial OPA348AIDBVR C363 |
| 2 | OPA333AQDBVRQ1 | zero-drift buffer, motor temp | 70 | OPA388-Q1 |
| 1 | EEH-ZC1H101P | NRC bulk 100 uF 50 V conductive-polymer hybrid aluminium, ZC | 45 | EEH-ZC1H121P (120 uF, same G case: 33.6  |
| 1 | CX3225GA40000D0PTVCC | 40 MHz crystal | 45 | NX3225GA-40M / SOSET 3225 40 MHz C538031 |

## BOM contribution by subsystem (all boards, ₹ @1k)

Where the money actually goes — cumulative share shows the Pareto: the first two rows are
~87 % of the electronics BOM, so those are the only two lines worth an RFQ fight.

| Subsystem | ₹ | share | cumulative | parts |
|---|---|---|---|---|
| SiC power modules | 54,000 | 75.6% | 75.6% | 3 |
| DC-link film caps | 3,200 | 4.5% | 80.1% | 16 |
| Hall sensors + AFE | 2,327 | 3.3% | 83.4% | 38 |
| Gate-power flybacks | 2,252 | 3.2% | 86.5% | 77 |
| MCU + clock + debug | 1,496 | 2.1% | 88.6% | 22 |
| VDC iso sensing + bias | 1,296 | 1.8% | 90.5% | 30 |
| Discharge (active+passive) | 1,146 | 1.6% | 92.1% | 33 |
| Vehicle connector + prot | 788 | 1.1% | 93.2% | 6 |
| FS26 SBC + LV input + wake | 691 | 1.0% | 94.1% | 40 |
| Gate drivers + networks | 659 | 0.9% | 95.1% | 129 |
| ASC buffer | 650 | 0.9% | 96.0% | 18 |
| misc | 604 | 0.8% | 96.8% | 59 |
| Module snubbers | 540 | 0.8% | 97.6% | 3 |
| Harness + pulldowns | 495 | 0.7% | 98.3% | 17 |
| HV entry/Y-caps/HVIL/studs | 302 | 0.4% | 98.7% | 14 |
| LV power (prot+LDO+boost) | 278 | 0.4% | 99.1% | 28 |
| Resolver AFE | 276 | 0.4% | 99.5% | 54 |
| CAN-FD x2 | 132 | 0.2% | 99.6% | 14 |
| Temps (module/board/motor) | 97 | 0.1% | 99.8% | 24 |
| Safety chain (EN/ASC/ILK) | 89 | 0.1% | 99.9% | 43 |
| VDC receivers (card) | 61 | 0.1% | 100.0% | 12 |
| Module NTC routing | 4 | 0.0% | 100.0% | 9 |

## Cost by category (all boards, ₹ @1k)

| Category | ₹ | share |
|---|---|---|
| power semiconductors | 55,986 | 78.4% |
| drive + control ICs | 10,539 | 14.8% |
| magnetics | 2,195 | 3.1% |
| connectors + sensors | 1,561 | 2.2% |
| misc | 430 | 0.6% |
| isolation | 231 | 0.3% |
| capacitors | 216 | 0.3% |
| protection + diodes | 132 | 0.2% |
| resistors | 94 | 0.1% |
| **TOTAL (electronics, ex-PCB/mech/busbar/coldplate)** | **71,383** | 100% |

The three HCS600FH120D3C1 modules dominate (as they should at this power class); every
other line is distributor-standard. Swapping the module vendor swaps one BOM line.

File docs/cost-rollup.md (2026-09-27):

# Traction Inverter — Full unit cost @1,000 units (rev A.22)

Complete ex-works build cost per inverter at a 1,000-unit run (India assembly, India+China
supply chain), on top of the generated electronics BOM (`docs/bom.md`, **₹72,983 @1k** across
the four assemblies). Figures are planning numbers (RFQ ±25 %); the two lines that move the
answer are flagged in §3.

## 1. Per-unit rollup (₹ @1k)

| # | Block | Low | Baseline | High | Notes |
|---|---|---|---|---|---|
| 1 | Electronics BOM (power + cap bank + discharge + card) | 66,000 | 72,983 | 96,000 | `bom.md`; low/high = module + film-cap quote swing (§3) |
| 2 | PCBs (power 6L 2–3 oz ~0.12 m² + card 6L + discharge 2L) | 4,500 | 5,300 | 6,100 | India/China fab @1k |
| 3 | PCBA (SMT ~750 placements + TH + AOI, 3 boards) | 2,500 | 3,300 | 4,100 | discharge board panelized 4-up |
| 4 | Liquid coldplate (FSW/gun-drilled Al, 3× EconoDUAL footprint, fittings) | 4,500 | 6,000 | 8,000 | ~360×160 mm, ≤0.05 K/W per switch to coolant (the S4 thermal-sim assumption — verify at thermal test) |
| 5 | Busbars (laminated DC bus + cap-bank assembly labor + 3 phase bars, plated) | 5,000 | 6,200 | 8,200 | the cap-bank sheet (2 of 4) is the busbar vendor's electrical drawing |
| 6 | Housing — **CNC** Al 6061 body + lid, seals, hard anodize | 6,500 | 8,500 | 11,000 | billet CNC as requested; gravity-cast + CNC faces ≈ ₹4–5.5k/unit + ₹4–7 L tooling (breaks even ~250 units) |
| 7 | HV connectors (DC-in 2P 300 A + HVIL; 3-phase out 3P 400 A) + coolant QCs | 4,000 | 5,200 | 6,500 | RADSOK-class; stud-through-gland saves ~₹2.5k if acceptable |
| 8 | Seals, Gore vent, EMC gasket, TIM (3 modules), fasteners, internal harnesses | 2,500 | 3,300 | 4,100 | incl. the 4-way discharge link + LEM harness |
| 9 | Assembly + EOL test (hi-pot, discharge-time, spin/power on B2B rig) + conformal coat | 2,500 | 3,200 | 4,000 | incl. rig amortization over 1k |
| 10 | Yield / scrap / warranty reserve (3 %) | 2,900 | 3,400 | 4,400 | |
| | **Ex-works cost per unit** | **≈ 100,900** | **≈ 116,900** | **≈ 152,700** | |

**Baseline: ≈ ₹1.17 lakh / unit ≈ $1,400 ≈ ₹530/kW ($6.4/kW).**
1,000 units ⇒ **≈ ₹11.7 Cr** parts + build (range ₹10.1–15.2 Cr).

### IGBT and 4XX SKUs (same boards — full comparison in [`variants.md`](variants.md))

Swapping to the HCG600FH120D3E1EA IGBT (₹9.5k/module planning vs ₹18k SiC) drops line 1 to
**₹47,483** and the ex-works baseline to **≈ ₹91k/unit (≈ ₹415/kW at 220 kW)** — at ≈0.45 pt
efficiency at the continuous point and 5 kHz switching. The 4XX IGBT SKU has the same
electronics BOM (600 V cans at the same planning price) plus ≈₹1.5k of heavier DC busbar and
HV connector for its ≈400 A DC peak: ≈ ₹0.92 L, **≈ ₹610/kW** at its 150 kW rating. Rev A.12
added +₹1,269/unit to every SKU: the reinforced UCC14141-Q1 biases and VOW3120 optos in place of the
uncertified QA01C-18/TLP152 pair (+₹1,006), the Samtec harness headers (+₹250) and the bias
passives; the 4XX SKUs gain ₹1,600 back from the bound Faratronic 4XX can. Both module quotes ride
the same hiitio RFQ. Rev A.13 adds +₹310/unit: the production UCC12051-Q1 biases (+₹260, the AEC-Q100 part promoted from "alternate" to primary), the exciter and motor-temperature terminal-fault protection (TVS, PTC, 63 V fuse) and the bias-LDO ballasts.

## 2. One-time NRE (not in the per-unit number)

| Item | ₹ |
|---|---|
| Coldplate + busbar + housing tooling/fixtures | 8–14 L |
| EOL back-to-back test rig (220 kW) | 15–25 L |
| DVT: CISPR 25 EMC + ISO 16750 environmental + thermal/durability | 35–70 L |
| **Hardware NRE subtotal** | **≈ 60–110 L → ₹6–11k/unit amortized over 1k** |
| ISO 26262 ASIL-D work products + assessment (if formal certification is pursued) | 1.5–4 Cr, program-level — the schematics carry ASIL-capable hardware mechanisms; the item definition, HARA, safety goals, FSC/TSC, FMEDA/FTA/DFA and the validation evidence are substantive engineering that can still change requirements — component capability is not product compliance (round 14, F21) |

## 3. What actually moves the number

1. **The hiitio module quote is 76 % of the electronics BOM.** Baseline assumes ₹18k (~$215)
   per HCS600FH120D3C1 at 3,000 pcs (3 × 18k = ₹54k of the ₹70.9k BOM). Chinese 600 A SiC
   EconoDUAL parts land $180–260 at this volume — get the written quote first. A Western
   module (~₹40–50k each at 1k) would add **+₹70–95k/unit** and make the inverter a ₹2 L
   product — and needs its own pin-map check (rev A.6: the Infineon FF6MR12W2M1H listed
   earlier is not an EconoDUAL-3 package).
2. **DC-link film caps**: 16 × Faratronic 20 µF at ₹300/can baseline (₹4.8k). Distributor
   pricing for Western 4-lead 40 µF alternates runs 2–4× that — stay on the Faratronic/
   Jianghai volume channel to hold baseline. The 4XX SKUs use 50 µF/600 V cans in the same
   positions (class part until the Faratronic RFQ).
3. **CNC vs cast housing**: at exactly 1k units billet CNC costs ~₹4k/unit more than
   casting+machining; casting pays for itself after ~250 units. Keep CNC for the first
   hundreds, tool the casting when the schedule firms.

## 4. Pricing guidance (if "price" = selling price)

Low-volume 200–300 kW/800 V SiC inverters (Cascadia CM350-class) sell at $4,000–7,000.
SiC SKU: at ₹1.15 L cost, ex-works **₹1.75–1.95 L** (35–40 % GM). IGBT SKU: at ≈₹0.90 L
cost, ex-works **₹1.35–1.55 L** at the same margin — it undercuts imported IGBT drives
(Curtis/Sevcon class tops out far below this power) while the SiC SKU undercuts
every imported option by ~2× while funding the NRE inside the first 1,000 units:

- Revenue @1k ≈ ₹17.5–19.5 Cr · COGS ≈ ₹11.5 Cr · gross ≈ ₹6–8 Cr vs ≈ ₹1.2 Cr hardware NRE.

Excluded throughout: motor/resolver, coolant pump/loop (vehicle-side), packaging & freight,
duties, software beyond the safety concept, and the formal ISO 26262 certification program.

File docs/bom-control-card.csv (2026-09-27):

Qty | Designators | Value | MPN | Manufacturer | Description | LCSC | Footprint | Price1k_INR | Ext_INR | Alt
3 | USNSU USNSV USNSW |  | HC5FW900-S | LEM | open-loop hall 900 A busbar transducer, 5 V ratiometric (GEN3 exact). INSULATION (N7): /SP1 is the reduced-insulation no-sleeve variant (2.5 kV/1 min, 3.6/2.7 mm) - phase busbar carries a >=1 kV DC insulating sleeve through the aperture, LEM to confirm for 850 VDC. SOURCING: LEM franchise/direct, listed-not-stocked at DigiKey — secure lead time early; only LCSC busbar hall (HAH1BVW S/06 600 A, C454763) is under-ranged and 0-stock. PINS (round 12, R1-F04; DS p.2): 1 V_ref (reference output, open), 2 V_out, 3 Gnd, 4 U_C 5 V, E1-E4 mass pins to Gnd — a PCB-mount THT device with no connector; it sits on the off-board carrier at the phase busbar and the carrier drawing derives from the 8-pin symbol. RL >= 10 k, CL <= 6.8 nF | CLASS | OffBoard | 700 | 2100 | HAH1BVW S/08 900 A class (LEM)
1 | UMCU |  | S32K396EHT1MJBST | NXP | lockstep M7 motor-control MCU (ASIL-D), eTPU/SDADC/SWG, 289-MAPBGA. PIN FREEZE (rev A.12): every ball bound in calculations/mcu-ballmap.json from the NXP GEN3 card schematic SPF-91122 rev C (sheets 8-13), anchored on the DS supply balls; every signal ball checked against its alternate-function list (PWM_1 A/B pairs, FAULT0/2, instance-separated ADCs, SDADC pairs, LPSPI3, FlexCAN0/1, FCCU, JTAG); 131 balls connected, 158 GPIO balls open. Production via NXP direct/franchise; LCSC marketplace lists this code C25786933 in tens only (proto) | CLASS | MAPBGA289 | 1400 | 1400 | S32K388 (same family, different ball map — re-freeze)
1 | JVEH |  | TE 770669-1 (AMPSEAL 23) | TE | 23-pos AMPSEAL PCB header, right-angle shrouded (CAN x2, KL30/KL15, resolver, motor temp, FAULT_OUT); mates 770680-1 plug + 770520 contacts. F60: 776231-1 was the 35-pos header (its drawing mates plug 776164) — rebound from the TE drawing, TE-770669-1.pdf in docs/datasheets | CLASS | AMPSEAL23 | 780 | 780 | 1-770669-x plating variants / Aptiv GT 280 family
1 | USBC |  | FS2633D | NXP | ASIL-D SBC: VPRE 5.4V buck / VCORE 1.5V buck / VREF 5V / LDO1 3.3V / LDO2 5V, Q&A WD, FCCU, FS0B/FS1B (GEN3 exact; pin map VERIFY vs DS). Production via NXP direct; LCSC lists MFS2633AMBA0AD C5191165 in single digits (proto); OTP variant must match | CLASS | HLQFP48 | 480 | 480 | FS2630 variants
9 | UUB1 UUB2 UVB1 UVB2 UVD1 UVD2 UVOF UWB1 UWB2 |  | OPA376AQDBVRQ1 | TI | VDC differential receiver (iso-amp diff pair -> single-ended to ADC) | CLASS | SOT23-5 | 28 | 252 | OPA320-Q1
1 | JICC |  | IPL1-120-01-L-D-K | Samtec | 40-way (2 x 20) 2.54 mm shrouded keyed header, card side — same family as JIC (right-angle IPL1-120-01-L-D-RA-K if the layout wants the harness flat); the cable carries an IPD1-20-D-K housing at each end | CLASS | HDR2x20-2.54 | 245 | 245 | TE AMPMODU Mod II 6-102618-8 / 2-826634-0 right-angle
1 | UEXD |  | ALM2402QPWPRQ1 | TI | dual power op-amp resolver driver, 8 Vpp H-bridge out (GEN3 exact — LCSC-stocked, 513 pcs); 14-pin PWP PowerPAD package (TI DS pin table; round 12 R1-F05/R2-F26: the BOM had said HTSSOP16) | C544754 | HTSSOP14-PWP | 180 | 180 | ALM2403QPWPRQ1 (DigiKey ships-today)
2 | UCAN1 UCAN2 |  | TCAN1042HGVDRQ1 | TI | CAN-FD 5 Mbps transceiver, VIO, AEC-Q100 — automotive grade stocked on LCSC | C132550 | SOIC8 | 55 | 110 | TCAN1042DRQ1 C118837 (loses 70 V fault tol.) / TJA1443
3 | UEXF UVMB1 UVMB2 |  | OPA348AQDBVRQ1 | TI | VMID buffers (exciter + sense mid-rails) — Q1 grade LCSC-stocked, 5.9k pcs | C2877787 | SOT23-5 | 25 | 75 | OPA365-Q1 / commercial OPA348AIDBVR C363280
2 | UMT1 UMT2 |  | OPA333AQDBVRQ1 | TI | zero-drift buffer, motor temp (GEN3 exact; LCSC 80 pcs + marketplace) | C2058544 | SOT23-5 | 35 | 70 | OPA388-Q1
1 | CLVC3 | 100uF | EEH-ZC1H101P | Panasonic | NRC bulk 100 uF 50 V conductive-polymer hybrid aluminium, ZC series G case (10 x 10.2 mm, 10.5 mm max height): 28 mOhm ESR at 100 kHz, 1.6 A rms ripple, 4000 h at 125 C, surge 1.25 x rated, AEC-Q200 (Panasonic ZC catalog). POLARISED — pin1 (+) on NRC, pin2 (-) on DGND; the sheet draws a plain C. Round 17 (F189): holds ISO 7637-2 pulse 2a (+112 V / 2 ohm) on NRC to <= 37.5 V (td read to 50 %, C -20 %, QLVS off) so the let-through TVS pair stays near its knee and the 40 V FS26 / TPS55340-Q1 ratings are kept; its capability for 500 such hits is a VR | CLASS | CAP-ALU-SMD-G-10x10.2 | 45 | 45 | EEH-ZC1H121P (120 uF, same G case: 33.6 V on the same pulse)
1 | Y1 |  | CX3225GA40000D0PTVCC | Kyocera | 40 MHz crystal (GEN3 exact; LCSC 20 pcs — thin, second-source noted) | C6009848 | X3225 | 45 | 45 | NX3225GA-40M / SOSET 3225 40 MHz C5380316 (PROTO ONLY: not AEC-Q200, 85 C, CL 12 pF retune)
1 | JSWD |  | FTSH-105-01-L-DV-K | Samtec | SURFACE-MOUNT (-DV = double-row vertical SMT; -K keyed shroud) — bound to the drawn Samtec_FTSH-105-01-L-DV-K land since round 23 (F215: a through-hole 1.27 mm header pattern was bound before); 10-pin 1.27 mm ARM Cortex debug header (2x5, keyed pin 7) - the drawn map: 1 VTref, 2 SWDIO/TMS, 3/5/9 GND, 4 SWCLK/TCK, 6 SWO/TDO, 8 TDI, 10 nRESET (A6-R10: was a 20-pin JTAG line) | CLASS | HDR2x5-1.27 | 45 | 45 | Harwin M50-3500542 / CNC Tech 3220-10-0300-00
1 | JLEM |  | T2M-105-01-L-D-TH-WT | Samtec | 2x5 2 mm hall-sensor harness header, latching (GEN3 exact; DigiKey ships-today) | CLASS | HDR2x5 | 45 | 45 | generic 2.0 mm 2x5 C64617 (no latch — debug builds only)
2 | TVSEN TVSEP |  | SMDJ7.0A-HRA | Littelfuse | resolver excitation line TVS, 3 kW UNIDIRECTIONAL, automotive/high-reliability grade AEC-Q101 (SMDJ-HRA-series.pdf p.2): V_RWM 7.0 V, V_BR 7.78-8.60 V at 10 mA, V_C 12.0 V at I_PP 250 A (10/1000 us; r_dyn 13.6 mOhm), I_R 200 uA at V_RWM, I_FSM 300 A (8.3 ms), P_M(AV) 6.5 W, DO-214AB = the same SMC pad. Round 19 (F203, xcheck19): was SMDJ8.5A-HRA (rounds 17-18) — the 7.0 V class halves the TVS power a tripped PTC leaves in it when an excitation line stays shorted to a 12-16 V battery with the card asleep (1.7-2.5 W instead of 3.8-4.3 W at 11.4-12.6 V; with the PTC coupled on the TVS island the junction stays <= 132 C where the 8.5A reached 148-171 C), keeps the rail-present clamp (<= 9.8 V at 40 A, 150 C) and the VMID-stuck fault dark with >= 2.4 V margin, and costs +0.043 Ohm on each IR-16 harness allocation (0.08 / 0.14 / 0.37 Ohm at 24 / 26 / 35 V). The energy at the sheet 8 A / 20 ms point falls to 1.4 J. Cathode on the protected node, anode on AGND (the excitation 0.4-4.6 V never exceeds V_RWM; leakage <= 1.4 % peak dip at 125 C on the x10/55 K bound). The plain SMDJ7.0A has no AEC-Q101 statement — the -HRA suffix does | CLASS | SMC | 22 | 44 | SMDJ7.0A (the plain series: same electricals as the -HRA, no AEC-Q101 statement — proto only; round 20 F205: the previous alt named the 8.5 V class, which is a different protection configuration — 9.44-10.40 V breakdown, 3.8-4.3 W parked trickle — and is EXCLUDED from the A.18 terminal-fault qualification)
1 | LSBC | 10uH | XAL4040-103MEC | Coilcraft | VPRE buck inductor 10 uH, AEC-Q200 — pairs with FPRE_OTP = 450 kHz per FS26 DS (LVPRE=10 uH at 450 kHz) | CLASS | XAL4040 | 35 | 35 | XGL4040-103
1 | FLVC |  | 0680L5000-05 | Bel Fuse | KL30 entry fuse, 5 A SLOW-BLOW ceramic 2410 (Bel 0680L, DS rev Jan2026): 125 V DC / 100 A and 75 V DC / 500 A interrupting, melting I2t 37 A2s at 10 x In (36 A2s under 10 ms), 19 mOhm cold, <= 0.23 V at 5 A, opens 200 % <= 120 s / 800 % 0.01-0.1 s, -55...125 C, thermal derating ~98 % at 85 C; AEC-Q compliant per Bel's internal AEC-Q test plan (the qualification report is a VR). Round 17 (F187): the MF-LSMF300/24X it replaces carried the WHOLE inverter (2.54 A at 9 V, 1.73 A at 13.5 V) on a 1.50 A hold at 85 C; this fuse runs at 0.65 of its 85 C / 80 % rerating at 9 V, and the hot-plug, pulse-1 and pulse-2a I2t each stay under 2 % of melting | CLASS | 2410 | 30 | 30 | Bourns SF-1206SA500W-2 (1206 slow blow, AEC-Q200 Rev. E, 65 VDC, I2t 5.4 A2s) — only if the OEM states a prospective fault current <= 50 A at the pin (its interrupting rating)
3 | USCH USCH2 USCH3 |  | 74LVC3G17DC-Q100 | Nexperia | triple Schmitt buffer (no input-transition limit, DS Table 6). USCH: clear one-shot -> ULAT2 /CLR, soft-off delay -> UAND2, FS0B -> UAND1 (round 7). USCH2: FLT diode-OR -> ULAT2 PRE + ASC gate, FS1B strap -> ULAT PRE, MCU discharge command -> harness QDIS_CMD (round 8 R7-02/R7-03) | CLASS | VSSOP8 | 10 | 30 | onsemi NLV37WZ17USG (US8, pin-identical)
1 | QLVS |  | DMP6023LEQ-13 | Diodes | power-board LV feed switch, P-ch -60 V, 28 mOhm max at -10 V, SOT-223, AEC-Q101/PPAP (DS39935 Rev 1, July 2017 — still marked Advance Information when re-checked 2026-09 (byte-identical download); production status is VR-20, the part ships from stock). On only while V5A is up: removes the ~150 mA parking drain of the always-fed power board (round 9, N17) | CLASS | SOT223 | 26 | 26 | DMP6023LSS-13 (SO-8, AEC-Q101)
1 | LCOR | 2.2uH | XAL4020-222MEC | Coilcraft | VCORE buck inductor 2.2 uH molded shielded, AEC-Q200 (FS26 Table 106, CORE_LSEL_OTP=0x02; eff window 1.5-2.9 uH; Isat per XAL4000 DS) | CLASS | XAL4020 | 25 | 25 | XGL4020-222 / any 2.2 uH Isat>=4 A shielded
2 | FVBH FVBL |  | MF-LSMF300/24X-2 | Bourns | card-side polyfuse per power-board feed chain (switched VBSW -> VBAT_H/L): 3.0 A hold at 23 C, 1.50 A at 85 C vs the 1.19 A worst chain at 9 V (exact part on LCSC) | C719172 | PTC2920 | 8 | 16 | RUILON SMD2920 class
2 | ULAT ULAT2 |  | 74LVC1G74DC-Q100 | Nexperia | D flip-flop with set/reset: ULAT = ASC latch (survives MCU reset), ULAT2 = fault latch. AEC-Q100 Grade 1, pin-identical to TI DCU (round 7: SN74LVC1G74DCUR is a catalog part, not Q100) | CLASS | VSSOP8 | 8 | 16 | SN74LVC1G74DCUR (catalog -40..125 C, LCSC C70285)
2 | FMT1 FMT2 |  | 0438.375WRA | Littelfuse | motor-temp line fuse 0603, 375 mA, 63 V DC, I2t 0.0041 A2s (16 us melting at the ~16 A of a KL30 short), R 1.25 R, -55...150 C, AEC-Q200 (438A series, EXTRACTED 31) — round 14 (F18): was a 350 mA class placeholder | CLASS | F0603 | 8 | 16 | Bourns SF-0603FP0375F-2 (65 V, no AEC-Q200)
2 | LCAN1 LCAN2 |  | ACT45B-101-2P-TL003 | TDK | CAN common-mode choke 100 uH (genuine TDK via DigiKey/Mouser; LCSC stocks drop-in clones) | CLASS | CMC1210 | 8 | 16 | cjiang FACT4532-101-2P-T C20624727 (5.9k stocked) / DLW43SH101XK2
1 | ULDOEX |  | NCV4276CDTADJRKG | onsemi | resolver-exciter protective LDO, 40 V-in 400 mA adjustable (DPAK-5): 12.1 V VEXD for the ALM2402 (18 V abs); at the 35 V test-B plateau (34.6 - 12.1) V x <= 0.06 A ~1.4 W, +13 K (round 17) | CLASS | DPAK5 | 14 | 14 | any 40 V 0.4 A adj LDO (NCV4275A)
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

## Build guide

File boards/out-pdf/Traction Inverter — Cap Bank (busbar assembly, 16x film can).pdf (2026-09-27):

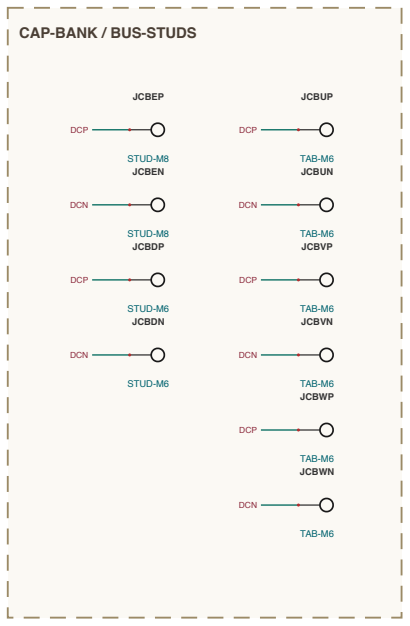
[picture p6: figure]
JCBDN; STUD-M6; JCBDP; JCBEN; STUD-M8; JCBEP; JCBUN; TAB-M6; JCBUP; JCBVN; JCBVP; JCBWN; JCBWP; DCN; DCP

### 220 kW pk Cap bank (HV, busbar) - 2 of 4 · rev A.23 · 2 sections · 26 components

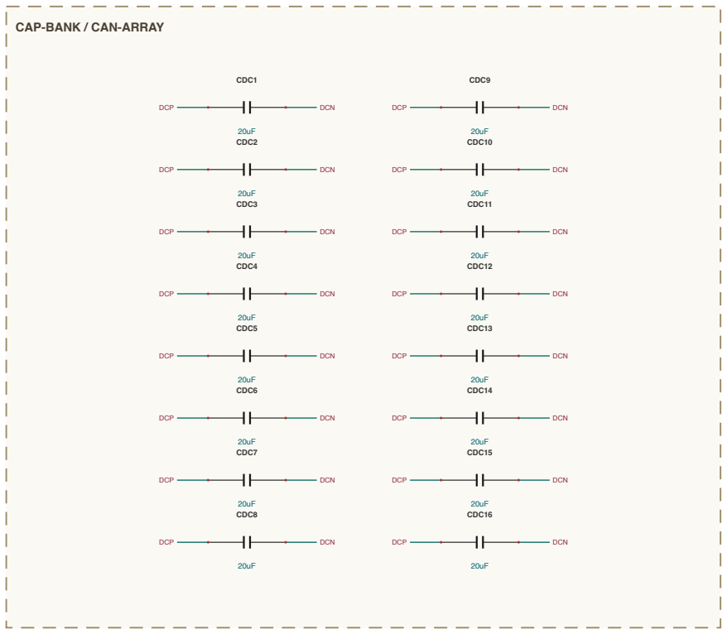
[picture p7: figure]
CDC1; CDC10; CDC11; CDC12; CDC13; CDC14; CDC15; CDC16; CDC2; CDC3; CDC4; CDC5; CDC6; CDC7; CDC8; CDC9; DCP; DCN

NET NAMING: U<ref>_<PIN> = node at that IC pin · R<stem>_M = series-pair midpoint · R<stem>_<nm> = tap between R<stem>n/m · all others are explicit design nets · same name on another sheet = same net, joined only at the named connector/stud/tab

CAP-BANK / BUS-STUDS | CAP-BANK / CAN-ARRAY

# rter — Cap bank (busbar assembly, 320 uF)

220 kW pk - Cap bank (HV, busbar), sheet 2 of 4 | 2026-09-23 · rev A.23

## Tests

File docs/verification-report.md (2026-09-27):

# Design Verification Report — rev A.23 (2026-09-27)

End-to-end verification of the 220 kW / 800 V traction inverter at actual operating corners
(V_bus 500–850 V · KL30 9–16 V · 10 kHz · 65 °C coldplate), worst-case component tolerances.
Three independent layers:

1. **Geometric pin-verify** (sheets vs netlist, `kicad5-verify.mjs`) — the sheets ship only at 100 %
2. **Structural ERC audit** (netlist vs design intent, `erc-audit.mjs`) — 0 fail, incl. a lock-in per fixed finding
3. **Numeric verification** (this report, `design-verify.mjs`): **158 PASS · 18 WARN · 0 FAIL** (+28 info)

A WARN is an item this analysis cannot close on paper — each names its bench or vendor gate.
Every SKU of the platform (8XX/4XX × SiC/IGBT — `loss-model.mjs`) is checked on the
same PCBs; losses and thermal use the shared model that `sim-verify.mjs` also runs.

## Findings log (F1–F36 rev A.3 campaign · F37–F46 rev A.4 · F47–F51 rev A.4.1 · F52–F57 rev A.4.2 · F58–F59 rev A.4.3 · F60–F62 rev A.5 docs audit · F63–F76 rev A.6 external review round 6 · F77–F89 rev A.7 review round 7 · F90–F97 rev A.8 review round 8 · F98–F105 its cross-check · F106–F113 rev A.9 review round 9 · F114–F119 its cross-check · F120–F122 rev A.10 schematic rechecks · F123–F134 rev A.11 system review · F135–F142 rev A.12 rechecks, pin freeze and production closure · F143–F158 rev A.13 round 14 · F159–F166 rev A.14 round 15 · F167–F173 rev A.15 round 16 (three rechecks of 32214be) · F174–F184 rev A.16 round 17 (gap closure) · F185–F189 rev A.16 round 17 (LV entry: test-B let-through, pulses 1/2a, FLVC, KL15) · F190–F198 rev A.17 round 18 (rechecks of 4425af9: diode pin numbers, the diversion through RSX, TVS/PTC coordination, RSX, acquisition-time firmware) · F199–F204 rev A.18 round 19 (rechecks of e315bf1: the 26 V endpoint, the ≥ 8 A trip-time law, the resolver time origin, the window criterion; the Marine sweep) · F205–F207 rev A.19 round 20 (rechecks of 00f6252: alternates and figure alignment) · F208 rev A.20 round 21 (rechecks of 551c405: the round-18 0.29 Ω in gate ㉘ and the QP-RX-04 fixture instruction, the last 8.5 V-era figures) · F209–F213 rev A.21 round 22 (rechecks of 0ff44d9: the §0.2 baseline; the layout handoff — footprint library and proof, 5-lead DPAK, thermal pads, 2-pad crystal) · F214–F220 rev A.22 round 23 (rechecks of 452de85: the R2R reference isolation, the SMT SWD header, the library's KiCad version, torque in field weakening, MTPA convergence, the BOM intro, the reference window) · F221–F232 rev A.22 round 23 (found by the closed-loop simulator bridge, the FW-38 and FW-42 agents: temperature-rate check, uncontrolled diode regeneration, torque slew, unset DTCs, ASC transient, the speed bound, the demodulator time centre, the resolver debounce, the NVM CRC blindness, slots, update throughput, alignment) · F233–F237 rev A.22 round 23, extension (the bridge's record at reboot, the CAN transport's missing ISO-TP reassembly, test code the target compiler caught, the 64-bit divide in ISR paths, host float rounding) · F238–F239 (the escape single frame dropped by every non-diagnostic service, the bridge without a boot record) · F240 rev A.23 round 24 (the SDADC reference on the same source as its supply — A20-F01 reopened, our round-23 disposition wrong) · F241 (a stopped slow ADC channel stayed valid — the three-state acquisition contract) · F242 (the inductance map's flux slope, the ripple limiter's interior — exact piece bounds) · F243–F244 (the temperature-rate latch overwritten by an open/short sample; the V_DC channels' sticky expiry and the first-read-stale stamp) — all fixed; review cross-reference in [`review-A6-disposition.md`](review-A6-disposition.md), [`review-A7-disposition.md`](review-A7-disposition.md) and [`review-A8-disposition.md`](review-A8-disposition.md))

| # | Severity | Finding | Fix |
|---|---|---|---|
| F90 | **HIGH** | A DESAT during latched ASC did not reach SPO: the faulted NSI6611 holds its own gate off (DS Fig. 8.11), but the healthy low sides stayed on through ASC, and a reset edge with the latch still set re-energised the faulted switch (R7-01/A7-N01) | UASCG: ASC_CMD = latch AND no-FLT on every path (FS1B-ASC included); FW-15 clears the ASC latch before the recovery; §4c transition table |
| F91 | MED | The FLT diode-OR reached the fault-latch preset at 111–135 ns/V (R7-02); buffering it exposed a 1N4148 low level at the Schmitt threshold (N12) | USCH2 74LVC3G17-Q100 on both latch presets; DFLT1/2 BAT46 |
| F92 | MED | Discharge TLP152 driven 470 Ω from the MCU pin: 6.4–6.8 mA vs 7.5 mA I_FLH max; the ASC opto proof used an assumed output drop (R7-03/A7-N03) | QDIS_CMD from USCH2 ch3, RQDL 270 Ω; both LEDs 9.6–14.2 mA from the guaranteed LVC V_OH point and V_F cold |
| F93 | MED | FW-16 boot test masked by RDY with gate power off; single-polarity (R7-04/A7-N02) | sensitized test with gate power up, before precharge, both polarities; coverage stated |
| F94 | MED | FAULT_OUT short to KL30 back-fed V5A through DSET/RENP2 (≈8 mA with V5A off) (A7-N04) | ZSET to ground, RENP2 removed: ≤ 0.6 mA into V5A |
| F95 | LOW | bom-gen wrote per-board CSVs before the semantic checks, so a failed run overwrote good outputs (A7-N05) | validate first, then publish atomically (temp + rename); mutation-tested |
| F96 | LOW | S4 called a 0.8 s junction pole conservative, and its case node delayed plate heating (R7-07, N14) | junction-case and case-plate static (an upper bound at every instant); +3 °C |
| F97 | LOW | Contract said the NSI6611 reset needs EN low ≥ t_FLT_MUTE; the DS (Fig. 8.8) has a mute time from the fault plus a ≥ t_RST_FIL pulse after it (N13) | §7 corrected; FW-15 unchanged |
| F98 | MED | Contract (cross-check R8X-01/02/03): FW-15 could leave the ASC latch set, so ASC returned at the reset edge with PWM held low (LS on with IN+ low — DESAT undocumented); FW-16 relied on sequence position, not measured V_DC/speed, for its HV-free step a; FW-16 d/e could not drop RDY while FS_GPIO1 held the flyback OR, and the FS_GPIO1 input was never tested | FW-15 always clears ASC (re-entry only through §4c); FW-16 measured preconditions, VCU precharge handshake, stored-pass arming; d/e drive FS_GPIO1 low, new g tests the OR; new h injects FLT (latch + mask covered in the field); FS1B_TDELAY = 0 required |
| F99 | MED | Dead-state gaps (R8X-06 + self-found): a Hi-Z USCH2 floated the fault-latch preset and the ASC mask — FW-16 passed with both gone; behind UASCG a Hi-Z ULAT floated the gate input (round 8 had moved the ASC pull-down off the latch) | RFCB 100 k on FLT_CMB_B (dead USCH2 = latched FLT: SPO, ASC masked, FW-16 b fails); RASCP moved to ASC_Q (dead ULAT = no ASC) |
| F100 | MED | QDIS_CMD sat next to V15 on the 4-way discharge header: a pin short put 15 V into USCH2 — which also carries both latch presets — and back into V5A (R8X-07) | header V15-GND-CMD-GND on both boards, locked by pin number |
| F101 | LOW | TLP152 LEDs 9.9 mA at the consistent cold corner, under the 10 mA recommended I_F; the model paired the 125 °C output resistance with the −40 °C V_F and omitted the far-end pulldown (R8X-04) | RASCL = RQDL = 261 Ω 1 %: 10.3–14.8 mA, judged against 10–15 mA |
| F102 | LOW | ZSET C5V6 "≤ 6.0 V" held only at 25 °C/5 mA: 6.62 V at a 35 V load dump on a KL30-shorted FAULT_OUT at 125 °C, over the USCH2 6.5 V abs max (R8X-05) | BZT52-B5V6 (±2 %): ≤ 6.34 V. C5V1 rejected — its soft knee through RFS2 would sag the released level toward V_T+ |
| F103 | LOW | FLT_LS_N had no glitch filter (CFLTF only on FLT_HS_N); a glitch now drops ASC and latches SPO with no automatic retry (R8X-12) | CFLTF2 100 pF |
| F104 | LOW | Lock-ins missed the FLT diode-OR, the FS1B back-feed by net and all of parts-db — a moved DFLT2 anode and an added FS1B pull-up both passed 854/0; two A.8 rows were fixed PASS (R8X-08) | ERC by net, pin number and first-match MPN per SKU; both rows computed; every new lock-in mutation-tested |
| F105 | LOW | S4 "true upper bound" held only for the assumed 60 s plate pole; VCC2 used 50 % FB-sense conduction on every corner; UASCG delay 4.4 ns (R8X-11/16) | static-plate bound reported (8XX IGBT 142 °C, WARN); per-corner conduction 1/0.5/0.2; 5.5 ns |
| F106 | MED | PSASC/PSQD are QA01C-18 (+18/−3 V), but F61 had bound the base QA01C sheet (+20/−4 V): the ASC timing assumed 18–24 V and the discharge gate ≈19.5 V (A8-N01) | QA01C-18 envelope 16.9–20.9 V modelled (Mornsun Fig. 1, line, tempco): ASC entry 7.07 → 7.52 µs, FW-06 end-point 905 → 906 V; MPN locked |
| F107 | MED | QDIS gate followed the bias rail through 47 Ω: up to 20.9 V against the +18 V recommended / +22 V abs, with the < 10 % load region extrapolated (A8-N02) | RQDG 1.5 k with RQDPD 10 k: V_GS 13.3–18.2 V with 1 % resistors (a divider, not a clamp — F122) |
| F108 | MED | FLT/RDY pulled up to V5A while the drivers' VCC1 is V5GD: 0.2 V over the FLT/RDY abs max (VCC1, no +0.3 V) at rail corners, and an undefined V5GD-loss state (A8-01; P-03, R8X-10) | pull-ups and the diode-OR pull-up on V5GD via harness pin 39 (DGND/HW_ID neighbours), RV5GP for an open pin: a lost V5GD is SPO, deterministically |
| F109 | MED | FW-16 allowed its ASC-actuating steps below 60 V: 0.62 J (8XX) / 1.54 J (4XX) at C_max into a latent high-side short (A8-N03) | eligibility < 12 V read (≤ 30/75 mJ), QDIS top-up from ≤ 60 V, n_ss from E_LL,pk |
| F110 | MED | Self-found (N17): the power board's LV side — V15 boost and four bias modules, V5GD, flyback controllers — ran on unswitched KL30, ≈150 mA while the vehicle sleeps | card-side P-FET switch (DMP6023LEQ) on V5A: ≤ 1 µA asleep |
| F111 | LOW | RFS4's 0.23 W case was only 16 V; 24/35 V reach 0.48/0.65 W and 0.23 W continues if FS1B is never released; BACKUP_SAFETY_PATH_FS1B = 1 repeated it through RSTB (A8-03) | RFS4 = ROHM ESR03EZPF1001 (0.27 W at 85 °C, ≈1.3 W/5 s); BACKUP_SAFETY_PATH_FS1B = 0 |
| F112 | LOW | The 10–15 mA LED window used Toshiba's typical V_F tempco as if guaranteed (A8-02) | ±28 % tempco band at every corner; the row judges the guaranteed I_FLH and abs-max margins first |
| F113 | LOW | "Battery opens in the SPO window = double fault" assumed independence (A8-G02) | §6 motor/vehicle release rule: energy-safe SPO, proven keep-connected, or the total-KL30-loss backup |
| F114 | MED | Cross-check R9X-01: a dead V5GD unpowers the AMC1311 LV sides, so the receivers sit at their +0.5 V offset — a valid-looking "0 V bus" (850 V could be reported as discharged); the N18 discriminator relied on it | V5GD read on PTB5 (RV5GP/RV5GS 2 × 47 k); V_DC invalid and SPO forced outside 4.75–5.25 V; also catches a back-powered, hovering V5GD (R9X-06) |
| F115 | MED | R9X-02: the drawn 2×20 harness numbers row by row, so VBAT faced ASC_CMD/QDIS_CMD/FLT_LS_N/RDY_HS and V5GD faced VDC1_P; "MICROFIT3-40" does not exist | HARNESS40 re-laid so VBAT and V5GD touch only ground or their own rail in both row-by-row and odd/even numbering (ERC checks both); class MPN until the layout picks the family |
| F116 | MED | R9X-03: ULDOEX (resolver exciter LDO) had INH on VBATC — ≈0.9 mA in FS26 LPOFF; the parking row summed the power board only | INH on V5A; the row now sums every unswitched load (≤ 43 µA at 25 °C) |
| F117 | LOW | R9X-04/10: QLVS turned on through its gate-drain charge (9–31 A into ≈45 µF at each wake), and a hot 2N7002's leakage × 100 k could half-close it while parked | 10 k/4.7 k gate network + 1 k/100 nF drain-gate: ≤ 1.1 A inrush, ≤ 0.5 V leakage drive |
| F118 | LOW | R9X-07/08: FW-16 trusted a 1 V low-voltage V_DC error (≈ ±9 V real); V5GD now follows V5A, so an FS26 restart erased a latched DESAT | read < 3 V or QDIS for 2 τ; FW-15 writes the DESAT to NVM and §9 gates arming on it |
| F119 | LOW | R9X-05/09/11/12/14: QLVS/QLVN G/S label swaps and a V5A–V5GD bridge passed the ERC; release rule (c) claimed the backup could cover the V5GD row; 25 V caps on the 20.9 V bias rails; RFS4 with FS1B held through a jump start unlisted; stale texts | pin-number and no-bridge locks; (c) limited to total KL30 loss; CASC/CQD 50 V; RFS4 held-case row (WARN, accepted); texts fixed |
| F120 | MED | Schematic recheck A9-S01: RDY_HS/RDY_LS (open-drain, 5.1 k to V5GD) drove 74LVC1G11-Q100 AND inputs directly at ≈20–100 ns/V against the 10 ns/V recommended limit; the round-7/8 "state-benign" rejection left the shutdown chain outside the datasheet | USCH3 74LVC3G17-Q100 on both RDY lines (RRDB dead-state pull-down); ERC by pin number |
| F121 | LOW | S9-01: RASCG (2.2 k) carries up to 0.12 W for as long as ASC is held, but was a generic 0603 (0.1 W at 70 °C → 82 mW at 85 °C) | ROHM ESR03EZPF2201 (0.33 W at 70 °C → 0.27 W at 85 °C); 2.2 k kept for the ASC timing |
| F122 | LOW | S9-02 and notes: discharge sheet heading "67.5k bleeder (58 s)"; "V_GS 13.4–18.1 V" read as a hard ceiling; the A9 disposition still quoted the interim pin-39 V5GD pin | 66 k (56 s nom / 65 s worst); 13.3–18.2 V with 1 % resistors ("a divider, not a clamp"); the final harness map quoted |
| F123 | **HIGH** | §6 release rule (a) accepted SPO on back-EMF alone and omitted the stored winding energy the diodes rectify into an isolated link: 1.5·L·I² = 61 J (8XX) / 84 J (4XX) with the 0.35 mH screening motor against 40 J of link headroom (R1-F01, R2-F08) | rule (a) now requires ½·C_min·(U_N² − V_max²) ≥ W_mag + W_emf from the motor's dq model; screening row (WARN): 8XX covers that motor only to 277 A rms, above it rule (b) |
| F124 | **HIGH** | Resolver exciter drawn with the MFB feedback pair swapped (4.7 nF output→summing node, 24 k output→inverting input): first-order 2 kHz roll-off, \|H(10 kHz)\| 0.18, so the S32K39 SWG (≤ 2.30 V pp) would have driven ≈ 0.7 V pp instead of 8 V pp (R2-F04) | textbook MFB 10k/24k/10k with 1.5 nF to ground and 220 pF feedback: f0 17.9 kHz, Q 0.70, |H| 1.85 → 7.7 V pp; SWG amplitude is the firmware knob; ERC by topology and value |
| F125 | **HIGH** | VDC-channel bias "MGJ2D150505SC" is not an existing order code, and the MGJ2 family is reinforced only to 150 Vrms (R1-F12, R2-F02/F03) | TI UCC12050 per channel (V_IOWM 1200 Vrms / 1697 VDC, VDE 0884-11 reinforced, the AMC1311's own class) behind its own NCV4276C from V15; 10 µF X7R both sides; ERC by pin |
| F126 | MED | The Hall open-wire pull-down claimed in README/design-basis since A.4 was never drawn (R1-F03) | R⟨ph⟩B0 100 k at each card input: open wire or dead sensor reads 0 V, outside the 0.2–4.8 V validity window now in FW-05 |
| F127 | MED | LEM HC5FW drawn as a 3-pin VCC/OUT/GND symbol; the device has 1 V_ref, 2 V_out, 3 Gnd, 4 U_C and E1–E4 mass pins and no connector (R1-F04) | 8-terminal symbol by DS number (V_ref open, E1–E4 to Gnd); the off-board carrier drawing derives from it; ERC by terminal number |
| F128 | MED | A resolver wire shorted to KL30 (shares the vehicle connector) injected ≈ 23 mA into an SDADC pin through 330 + 120 Ω against the S32K39's 3 mA limit (operating and absolute maximum), and both legs pulled 20 mA into the VMID buffer through the 680 Ω bias (R2-F13, R1-F20) | RSINF/RCOSF and RSIN/RCOS → 10 k: 1.0 / 1.8 / 2.9 mA at 16 / 24 / 35 V, buffer 2.7 mA; caps rescaled (47 p + 100 p differential, 22 p common-mode on both legs — the P-only caps converted CM to DM): corner 47 kHz, −12° on both channels; SWG given its 47 pF load |
| F129 | LOW | VREF5 sat at 3.3 µF nominal, the FS26 upper limit, before tolerance (R2-F11) | CSB5 2.2 µF → 1 µF (0805 X7R 16 V): 2.1 µF nominal, 1.4–2.3 µF effective over tolerance, bias, temperature and aging |
| F130 | **HIGH** | LV-entry coordination (R1-F14, R2-F10, found by the Opus check): the notes described the classic TPSMC24CA (V_BR 22.8–25.2 V), which conducts at the 24 V/60 s jump start and, in an ISO 16750-2 test B at Ri ≤ 2 Ω, takes more than the (extrapolated) 400 ms capability; at 0.5 Ω the polyfuse then trips inside the pulse, sees ≈ 30 V against its 24 V V_max and latches until a KL30 cycle; the archived datasheet was the -VR series | TPSMC24CA-VR bound explicitly (AEC-Q101, 24 V stand-off, V_BR 26.7–29.5 V, same pad and price): dark at 24 V, clamps ≤ 33 V under the boost's 34 V abs max; test B covered on paper at Ri ≥ 4 Ω, the OEM's Ri is gate ㉗ (≤ 2 Ω: TVS pulse test or 35 V-rated rails). Polyfuse kept (the 33 V part holds 1.17 A hot against the 1.19 A worst chain) |
| F131 | LOW | UEXD (ALM2402QPWPRQ1) bought as "HTSSOP16"; the PWP package is 14-pin (R1-F05, R2-F26) | footprint HTSSOP14-PWP; ERC asserts the 14-pin package against the symbol |
| F132 | LOW | Board NTCs drawn as 2-pin headers, bought as 0603 NTCs (R2-F27) | on-board RTAMB/RTHS 0603 (symbol = BOM) |
| F133 | LOW | kicad5-verify exited 0 on an empty page set (R2-F29) | fails unless 4 sheets and ≥ 1500 pins were compared |
| F134 | LOW | Contract and document defects: FW-05 threshold in A rms; §6 merged "contactor open" with "BMS limit 0"; FW-15 "NVM first" ahead of the safe action; FW-02 τ bands overlap; HW_ID "pin 40"; "LQFP-176"; stale "inside 6 µs" IGBT text; ALT field offered M7 rectifiers and a 3-lead TO-247; CAN termination fixed; FW-18 silent on invalid witnesses; S6 double-update unstated (R1-F02/F11/F18/F23/F24/F25/F27, R2-F18/F19/F24/F33/F34/F35) | all corrected: instantaneous ±601/±707 A; rows split; retained-RAM latch, queued NVM; plausibility wording + EOL measurement; pin 2; 289-MAPBGA; RR04 wording; ALT = qualify-before-use; endpoint DNP option; "unknown, never safe"; delay stated |
| F135 | **HIGH** | Round 13 (A11-R01 ×2): rule (a) was fixed but the §6 matrix stayed speed-split — standstill freewheel of the 0.35 mH screening motor at 340 A rms takes an isolated 8XX link to 1089 V from the trip; the KL30 row still cited the back-EMF test and rule (b) applied only at n ≥ n_x | column note: the energy condition applies in both columns; battery-path-lost row at n < n_x uses FW-06 LS-ASC as the energy sink; KL30 row cites rule (a); rule (b) at every point where (a) fails, barred where the premise is the lost battery |
| F136 | MED | Round 13 (A11-R02/R03): the 10 k injection bound assumed a powered 5.7 V clamp — unpowered, 35 V gives 3.42 mA against the 3 mA absolute limit; and the SDADC anti-alias capacitor (C_AAF 180 pF min, Table 38) had been cut to 100 pF | RSINF/RCOSF and RSIN/RCOS 12 k (2.92 mA at 35 V into 0 V, −1 % R; VMID buffer 5.4 mA); 220 pF C0G at the pins; corner 23 kHz, −24° both channels; the channel-matching bound is stated (1.3° from the Z_DIFF corners by the verifier's amplitude-ratio form; the recheck's 1.09° used a phase form — the larger is carried) instead of "ratio-cancelled" |
| F137 | LOW | Round 13 (A11-R05/N01): the verifier's guard counted JSON pages, not distinct assemblies | exact set {power, capbank, disch, card}, no duplicates, ≥ 1500 pins |
| F138 | LOW | Round 13 (A11-R06 / R03): the LV-entry argument used the commercial TPS55340's 34 V absolute maximum (and an older row 45 V) — the fitted -Q1 part is 38 V recommended / 40 V absolute, so the "≥ 42 V boost" premise was false | model, BOM and gate ㉗ corrected; the commercial part marked PROTO ONLY |
| F139 | LOW | Round 13 (R04): the V_DC bias LDO thermal row assumed 40 K/W; the NCV4276C DPAK reference pad is 58.5 K/W and the UCC12050's 50 mA is typical | 0.76 W worst → Tj ≈ 129 °C at 85 °C on the reference pad (WARN); ≥ 1.2 in² 2 oz copper per LDO in dfm §4; measured at the hot first article |
| F140 | **HIGH** | Pin freeze (rev A.12): the A.4 "GEN3-exact" MCU port list was symbolic and partly wrong — PTG10 has no PWM output, PTB0/PTB4/PTB5/PTF5 no ADC, PTB2/PTB3 are external-mux ADDRESS outputs, PTA10 is JTAG_TDO, PTA11–13 do not exist on the 289-MAPBGA | all 289 balls bound from SPF-91122 rev C (anchored on the DS supply balls): PWM_1 A/B pairs on PTC31/PTA6, PTC30/PTA7, PTC29/PTC8 with FAULT0/FAULT2 on PTC26/PTC25; 17 analog inputs on ADC-capable balls with the currents on three instances; SDADC pairs as GEN3; FS26 48 pins verified; ERC by ball |
| F141 | **HIGH** | Barrier parts without a published working voltage (gates ⑪/㉔): the TLP152 optos and the QA01C-18 bias modules on the 850 V link carried UL1577 test voltages only, no V_IORM/V_IOWM | Vishay VOW3120-X017T (V_IORM 1414 Vpk, DIN EN 60747-5-5, CPG ≥ 10 mm) and TI UCC14141-Q1 (reinforced, V_IORM 1414 Vpk / V_IOWM 1000 Vrms, DS §7.5 — certificates listed "planned", gate kept for the status) drawn on both boards in the single-output configuration; LED resistors 270 Ω for the lower V_F; Y-caps bound to Vishay VY1 (Y1 500 VAC / 1500 VDC) |
| F142 | MED | Orderability: the harness connector, the 4XX capacitor can and the discharge resistors were class placeholders ("HARNESS-2x20-CLASS", generic can, generic 10 W) | Samtec IPL1-120-01-L-D-K / IPD1-20-D-K / CC79L crimps (−55…125 °C, 3.8 A/pin, positive latch; no 2.54 mm family states AEC-Q200 — A-Series MPN to confirm, pin numbering to confirm against the print), Faratronic C3D1U506KFAA382, TT SQP10-470RJB15 / -220RJB15 |
| F143 | **CRITICAL** | Round 14 (A12-R01/R02): two MCU supply balls were wrong in the A.12 freeze — H5 (V15, the 1.5 V core input, 2.75 V abs max) carried the 5 V VREF5; J7 (V25, the 2.5 V flash-regulator output) was grounded | H5 → V15S; J7 → V25 + CV25 220 nF; the whole map re-derived against NXP's GEN3 net report (U513, 244 balls): every supply ball and 164/165 port names agree; the four signals on GEN3-open balls moved to netlist-confirmed balls (B5/T15/D5/U4) |
| F144 | **HIGH** | Round 14 (A12-R03): the exported MCU symbol numbered its pins 1…130 with the ball only in the name — not a physical package binding | pages.mjs emits the ball ID as the KiCad pin NUMBER for '<ball>_<signal>' labels; kicad5-verify fails unless every MCU X record's number equals the manifest ball for its label |
| F145 | LOW | Round 14 (A12-R04): the NMOS ballast network lacked NXP's 1 nF gate-stability capacitor (DS Table 13) | CBAL 1 nF C0G, NMOS_CTRL to VSS |
| F146 | **CRITICAL** | Round 14 (A12-R05): the DESAT ISR called br_spo(true), dropping the undelayed MCU_GATE_EN and bypassing the 22–53 µs hardware FLT → DRV_EN delay that protects the driver's soft turn-off | bridge module enforces a DESAT hold (CAL 60 µs ≥ the RC upper corner) for every caller; PWM inhibit stays immediate; regression tests |
| F147 | **HIGH** | Round 14 (A12-R06): now_ms() = us/1000 of a wrapping 32-bit counter — the ms value jumped 4 294 967 → 0 after 71.6 min, so unsigned ages became ≈ 4.29·10⁹ ms (false VCU/BMS staleness) | 64-bit monotonic µs clock in the HAL, ms derived from it (wraps at 2³² ms consistently); every /1000 timestamp producer audited; wrap-straddling tests |
| F148 | **HIGH** | Round 14 (A12-R08): keep_hv was speed-only while §6 credits battery retention at every speed — a low-speed high-current SPO relied on the battery without requesting it (0 rpm, 340 A: rule (a) false, rule (b) true, keep_hv false) | keep_hv derived from actual reliance on rule (b), held until rule (a) holds or ASC is active; propagated to the CAN status; lost-battery rows cannot borrow (b) |
| F149 | MED | Round 14 (A12-R07): the bias-LDO model used 76 mA (50 mA typ × 1.2) — the production UCC12051-Q1 draws 80 mA MAX at no load (96 mA with the AMC1311 → 0.96 W, Tj 141 °C) | R5L 47 Ω ballast per LDO (LDO ≈ 0.5 W, Tj ≈ 116 °C; resistor 0.45 W in a 2512); UCC12051QDVERQ1 promoted to the primary MPN, UCC12050 the proto fit |
| F150 | **CRITICAL** | Round 14 (F01): the target fault routing (IMCR indices / SSS for PTC26/PTC25 → PWM_1 FAULT0/2) was placeholder 0u | placeholders are a build error; the host build reports the route unbound and arming is refused (fail closed) until the RM-derived values are filled and the route validated |
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

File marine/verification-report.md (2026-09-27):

# Marine Series — Verification Report (2026-09-27)

Generated by `marine/calc/marine-verify.mjs`. **87 PASS · 23 WARN · 0 FAIL** (+41 info).
Basis: 45 °C coolant · Tj ≤ 125 °C continuous / 150 °C overload · 110.00000000000001 % / 60 s overload ·
PF 0.85 at modulation 1.1 · power cycling ≥ 2× a 20-year ferry mission. See [design-basis](design-basis.md).

### Cell rating — M8 IGBT (HCG600FH120D3E1EA, 500–850 V, 5 kHz)

| Check | Value | Limit | Verdict | Note |
|---|---|---|---|---|
| Continuous current (S1) and its binding limit | **300 A rms** (bound by caps) | thermal 329 A · life 312 A · caps 303 A · sensor 417 A | ℹ️ | thermal: Tj ≤ 125 °C at 45 °C coolant, 850 V, motoring and regeneration; life: LESIT ≥ 2× mission with 20 % margin; caps: Kolar worst 0.65·I at 80 % of the can rating; sensor: the FW-05 trip ±583 A (1.25 × √2 × the 110 % current, instantaneous amperes — Road round 12) inside 90 % of range |
| Continuous power (S1) | **214 kW @720 V** · 148 kW @500 V · 252 kW @850 V | - | ℹ️ | PF 0.85, 5 % modulation reserve; P ∝ V_dc below the motor's base-speed voltage |
| IGBT Tj, continuous motoring (300 A, 850 V) | 117 °C (528 W: cond 167 + sw 361) | 150 °C Tvjop | ✅ PASS | 78% of limit · switching ∝ V^1.3; T+D share the coldplate footprint |
| Diode Tj, continuous regeneration | 97 °C (216 W) | 150 °C | ✅ PASS | 65% of limit · crash stop / braking puts full current through the FWD |
| Overload 110 % / 60 s (330 A), steady-state bound | 125 °C | 150 °C | ✅ PASS | 84% of limit · a 60 s step is inside the module+plate τ; the steady-state bound over-states it |
| Power cycling, ferry duty: dock↔cruise (85 % load, 720 V, ΔTj 52 K, Tj 97 °C) | LESIT N_f ≈ 0.73 M cycles | 2 × 0.22 M (30 crossings/day × 20 years) | ✅ PASS | 60% of limit · LESIT (Held 1997) — ≈2× more conservative than Semikron AN 21-001 at these mean temperatures; hiitio power-cycling curves are the gate |
| **Tug-duty rating**: 220 A → 157 kW (full-power pulses, ΔTj 44 K) | LESIT N_f ≈ 2.12 M pulses | 2 × 0.79 M (6 jobs × 20 pulses/day × 330 days × 20 years) | ✅ PASS | 75% of limit · 73 % of the ferry rating — the pulse count is an estimate; an owner's measured profile moves this line, not the hardware |
| Semiconductor efficiency at cruise (182 kW) | 98.57 % (2632 W) | - | ℹ️ | 6 switches, hot VCEsat |

### Cell rating — M10 IGBT (HCG600FH170D3E1/E1A, 650–1100 V, 3 kHz)

| Check | Value | Limit | Verdict | Note |
|---|---|---|---|---|
| Continuous current (S1) and its binding limit | **270 A rms** (bound by life) | thermal 290 A · life 273 A · caps 369 A · sensor 417 A | ℹ️ | thermal: Tj ≤ 125 °C at 45 °C coolant, 1100 V, motoring and regeneration; life: LESIT ≥ 2× mission with 20 % margin; caps: Kolar worst 0.65·I at 80 % of the can rating; sensor: the FW-05 trip ±525 A (1.25 × √2 × the 110 % current, instantaneous amperes — Road round 12) inside 90 % of range |
| Continuous power (S1) | **254 kW @950 V** · 174 kW @650 V · 294 kW @1100 V | - | ℹ️ | PF 0.85, 5 % modulation reserve; P ∝ V_dc below the motor's base-speed voltage |
| IGBT Tj, continuous motoring (270 A, 1100 V) | 119 °C (575 W: cond 174 + sw 401) | 150 °C Tvjop | ✅ PASS | 79% of limit · switching ∝ V^1.3; T+D share the coldplate footprint |
| Diode Tj, continuous regeneration | 96 °C (211 W) | 150 °C | ✅ PASS | 64% of limit · crash stop / braking puts full current through the FWD |
| Overload 110 % / 60 s (297 A), steady-state bound | 127 °C | 150 °C | ✅ PASS | 85% of limit · a 60 s step is inside the module+plate τ; the steady-state bound over-states it |
| Power cycling, ferry duty: dock↔cruise (85 % load, 950 V, ΔTj 54 K, Tj 99 °C) | LESIT N_f ≈ 0.59 M cycles | 2 × 0.22 M (30 crossings/day × 20 years) | ✅ PASS | 74% of limit · LESIT (Held 1997) — ≈2× more conservative than Semikron AN 21-001 at these mean temperatures; hiitio power-cycling curves are the gate |
| **Tug-duty rating**: 190 A → 179 kW (full-power pulses, ΔTj 44 K) | LESIT N_f ≈ 2.37 M pulses | 2 × 0.79 M (6 jobs × 20 pulses/day × 330 days × 20 years) | ✅ PASS | 67% of limit · 70 % of the ferry rating — the pulse count is an estimate; an owner's measured profile moves this line, not the hardware |
| Semiconductor efficiency at cruise (216 kW) | 98.69 % (2870 W) | - | ℹ️ | 6 switches, hot VCEsat |

### Cell rating — M8-SiC (small craft) (HCS600FH120D3C1 (SiC), 500–850 V, 10 kHz)

| Check | Value | Limit | Verdict | Note |
|---|---|---|---|---|
| Continuous current (S1) and its binding limit | **300 A rms** (bound by caps) | thermal 361 A · life 316 A · caps 303 A · sensor 417 A | ℹ️ | thermal: Tj ≤ 125 °C at 45 °C coolant, 850 V, motoring and regeneration; life: LESIT ≥ 2× mission with 20 % margin; caps: Kolar worst 0.65·I at 80 % of the can rating; sensor: the FW-05 trip ±583 A (1.25 × √2 × the 110 % current, instantaneous amperes — Road round 12) inside 90 % of range |
| Continuous power (S1) | **214 kW @720 V** · 148 kW @500 V · 252 kW @850 V | - | ℹ️ | PF 0.85, 5 % modulation reserve; P ∝ V_dc below the motor's base-speed voltage |
| MOSFET Tj, continuous motoring (300 A, 850 V) | 105 °C (475 W: cond 257 + sw 199) | 175 °C Tj max | ✅ PASS | 60% of limit · switching ∝ V^1.3; T+D share the coldplate footprint |
| Regeneration | same die (synchronous rectification) | - | ℹ️ | reverse conduction is in the MOSFET row above; SiC loss is symmetric in motoring and braking |
| Overload 110 % / 60 s (330 A), steady-state bound | 114 °C | 150 °C | ✅ PASS | 76% of limit · a 60 s step is inside the module+plate τ; the steady-state bound over-states it |
| Power cycling, ferry duty: dock↔cruise (85 % load, 720 V, ΔTj 42 K, Tj 87 °C) | LESIT N_f ≈ 0.91 M cycles | 2 × 0.22 M (30 crossings/day × 20 years) | ✅ PASS | 48% of limit · LESIT (Held 1997) — ≈2× more conservative than Semikron AN 21-001 at these mean temperatures; SiC ×0.33; hiitio power-cycling curves are the gate |
| **Tug-duty rating**: 235 A → 167 kW (full-power pulses, ΔTj 37 K) | LESIT N_f ≈ 2.02 M pulses | 2 × 0.79 M (6 jobs × 20 pulses/day × 330 days × 20 years) | ✅ PASS | 79% of limit · 78 % of the ferry rating — the pulse count is an estimate; an owner's measured profile moves this line, not the hardware |
| Semiconductor efficiency at cruise (182 kW) | 98.9 % (2023 W) | - | ℹ️ | 6 switches, hot VCEsat |

### Evaluation — per-cell options for the MW end (thermal + life limits; caps and sensor sized to fit)

| Check | Value | Limit | Verdict | Note |
|---|---|---|---|---|
| M8-HP (eval: 1200 V/900 A IGBT) | **430 A rms → 306 kW @720 V** (213–361 kW) · tug 310 A → 221 kW · 98.76 % at cruise | Tj ≤ 125 °C @45 °C and life, 3 kHz | ℹ️ | needs ≈23 × 15 A cans (vs 16 on the Road bank) and a ±1500 A-class sensor |
| M10-SiC (eval: 1700 V/800 A SiC) | **325 A rms → 305 kW @950 V** (209–354 kW) · tug 240 A → 225 kW · 98.93 % at cruise | Tj ≤ 125 °C @45 °C and life, 8 kHz | ℹ️ | needs ≈18 × 15 A cans (vs 16 on the Road bank) and a ±1500 A-class sensor |
| M10-2P (eval: 2 × 1700 V/600 A per switch) | **495 A rms → 465 kW @950 V** (318–539 kW) · tug 350 A → 329 kW · 98.56 % at cruise | Tj ≤ 125 °C @45 °C and life, 3 kHz | ℹ️ | needs ≈27 × 15 A cans (vs 16 on the Road bank) and a ±1500 A-class sensor; two modules per switch share one driver via a gate booster (new power PCB) |

### DC link — M8 IGBT (16 × Faratronic C3D1M206KFSA382 20 µF/1100 V (Road 8XX bank))

| Check | Value | Limit | Verdict | Note |
|---|---|---|---|---|
| Ripple per can, continuous 300 A (Kolar worst M/cosφ) | 12.2 A | 15.4 A | ✅ PASS | 79% of limit |
| Ripple per can, overload 330 A | 13.4 A | 15.4 A | ✅ PASS | 87% of limit · 60 s is inside the can's thermal τ |
| Can U_N(85 °C) vs OV trip 880 V | 880 V | 1000 V | ✅ PASS | 88% of limit |
| V_max + ½ΔV_pp (in-period ripple at 5 kHz) vs OV trip | 850 + 21 V (ΔV_pp 41 V at M 1.1, cosφ 0.85) | 880 V trip | ✅ PASS | 68% of limit · 320 µF; switch-state run, battery supplies the mean; at 3 kHz it would reach the trip — why M8 switches at 5 kHz |

### DC link — M10 IGBT (20 × 15 µF/1300 V class can (RFQ))

| Check | Value | Limit | Verdict | Note |
|---|---|---|---|---|
| Ripple per can, continuous 270 A (Kolar worst M/cosφ) | 8.8 A | 15 A | ✅ PASS | 58% of limit |
| Ripple per can, overload 297 A | 9.6 A | 15 A | ✅ PASS | 64% of limit · 60 s is inside the can's thermal τ |
| Can U_N(85 °C) vs OV trip 1150 V | 1150 V | 1300 V | ✅ PASS | 88% of limit |
| V_max + ½ΔV_pp (in-period ripple at 3 kHz) vs OV trip | 1100 + 33 V (ΔV_pp 66 V at M 1.1, cosφ 0.85) | 1150 V trip | ✅ PASS | 66% of limit · 300 µF; switch-state run, battery supplies the mean |

### DC link — M8-SiC (small craft) (16 × Faratronic C3D1M206KFSA382 20 µF/1100 V (Road 8XX bank))

| Check | Value | Limit | Verdict | Note |
|---|---|---|---|---|
| Ripple per can, continuous 300 A (Kolar worst M/cosφ) | 12.2 A | 15.4 A | ✅ PASS | 79% of limit |
| Ripple per can, overload 330 A | 13.4 A | 15.4 A | ✅ PASS | 87% of limit · 60 s is inside the can's thermal τ |
| Can U_N(85 °C) vs OV trip 880 V | 880 V | 1000 V | ✅ PASS | 88% of limit |
| V_max + ½ΔV_pp (in-period ripple at 10 kHz) vs OV trip | 850 + 10 V (ΔV_pp 21 V at M 1.1, cosφ 0.85) | 880 V trip | ✅ PASS | 35% of limit · 320 µF; switch-state run, battery supplies the mean |

### Gate drive — M8 IGBT

| Check | Value | Limit | Verdict | Note |
|---|---|---|---|---|
| DESAT worst detection + soft-off (82 pF blank) | 4.81 µs @400 mA typ · 10.29 µs @100 mA DS min (detect 2.98 µs) | 6 µs @800 V → 5 µs at 850 V | 🟡 WARN | RELEASE GATE (Road RR04/③): typ is 96 % of the derated rating, the 100 mA corner does not close — NOVOSENSE I_STO distribution + hiitio's SC statement at 850 V and the 16.9 V gate-rail corner + contained SC test (Cies 106 nF from 16.9 to 10 V); firmware now holds MCU_GATE_EN for a CAL 60 µs minimum before a software caller can drop it (Road round 14/A.13), so the ISR can no longer race this soft-off — clears both corners above with margin |
| DESAT trip at the switch (2 × US1M, 4.7 k) | 4.25–7.16 V | > VCEsat 1.62 V at the 110 % peak, hot | ✅ PASS | 38% of limit · no nuisance trip at the worst-low corner; short circuit drives V_CE to the bus |
| Gate-power demand per bank @5 kHz | 2.01 W | 2.81 W worst-part capacity (RT 8.2 k) | ✅ PASS | 72% of limit · Qg 4.36 µC full-swing, Road method |

### Gate drive — M10 IGBT

| Check | Value | Limit | Verdict | Note |
|---|---|---|---|---|
| DESAT worst detection + soft-off (82 pF blank) | 4.35 µs @400 mA typ · 8.44 µs @100 mA DS min (detect 2.98 µs) | 6 µs @1000 V → 4.8 µs at 1100 V | 🟡 WARN | RELEASE GATE (Road RR04/③): typ is 91 % of the derated rating, the 100 mA corner does not close — NOVOSENSE I_STO distribution + hiitio's SC statement at 1100 V and the 16.9 V gate-rail corner + contained SC test (Cies 79 nF from 16.9 to 10 V); firmware now holds MCU_GATE_EN for a CAL 60 µs minimum before a software caller can drop it (Road round 14/A.13), so the ISR can no longer race this soft-off — clears both corners above with margin |
| DESAT trip at the switch (3 × US1M, 4.7 k) | 3.65–6.55 V | > VCEsat 1.92 V at the 110 % peak, hot | ✅ PASS | 53% of limit · no nuisance trip at the worst-low corner; short circuit drives V_CE to the bus |
| Gate-power demand per bank @3 kHz | 1.59 W | 2.81 W worst-part capacity (RT 8.2 k) | ✅ PASS | 57% of limit · Qg 5.01 µC full-swing, Road method |

### Gate drive — M8-SiC (small craft)

| Check | Value | Limit | Verdict | Note |
|---|---|---|---|---|
| Gate-power demand per bank @10 kHz | 1.33 W | 2.31 W worst-part capacity | ✅ PASS | 58% of limit · Road SiC numbers |
| Short-circuit withstand | SiC t_SC not published by hiitio | 3.1 µs Road DESAT reaction | 🟡 WARN | Road VERIFY ③ — hiitio letter + contained SC test before any marine SiC delivery |

### Discharge — M8 IGBT (bleeder 2 × 6 × 22 k · active 4 × 470 Ω)

| Check | Value | Limit | Verdict | Note |
|---|---|---|---|---|
| Passive 850→60 V, worst (R+5 %, C+10 %) | 65.3 s | 120 s service rule | ✅ PASS | 54% of limit · nominal 56.5 s |
| Bleeder V on the worst-tolerance resistor @850 V | 153.9 V | 200 V working (2512) | ✅ PASS | 77% of limit |
| Bleeder W/resistor @850 V (R−5 %) | 0.96 W | 2 W | ✅ PASS | 48% of limit · standing loss 11 W |
| Active + passive 850→60 V, worst corner | 1.81 s | 5 s (IEC 61800-5-1 accessible-part rule) | ✅ PASS | 36% of limit |
| Energy per 10 W wirewound (C+10 %) | 32.1 J | 100 J single-pulse | ✅ PASS | 32% of limit · firmware ≤ 3 discharges / 5 min |
| V per wirewound | 212.5 V | ≥350 V axial class | ✅ PASS | 61% of limit |
| QDIS switch | 0.45 A pk at 850 V | 1200 V / 42 A (Road part) | ✅ PASS | fully enhanced, no linear region; gate through the kept 1.5 k/10 k divider, now 11.6–16.3 V from the UCC14141-Q1 (Road A.12; low end set by the VOW3120's guaranteed V_OH ≥ V_CC − 4 V) |
| QDIS stuck ON with the battery connected | 384 W continuous (96 W per resistor) | not survivable by 10 W parts | 🟡 WARN | bounded as on the Road (F23): fire only with the DC breaker reported OPEN; now detected at the next contactor opening → latched no-re-energise DTC + contactor-open request (Road round 14/A.13, replaces the earlier precharge-only check); no-flame per the TT/Welwyn SQP10 statement (will not burn or emit incandescent particles under any condition of applied temperature or overload) holds at any overload, so it covers this power without the Road A6-R11 70–100 W qualification window; fail-open TIME at this power is a QP-MA-05 characterisation, not a release gate (Road gate ㉖) |
| FW-16 self-test residual energy (read < 3 V, or QDIS for 2 τ from < 60 V) | ≤ 26 mJ (read) · ≤ 15 mJ (QDIS 2 τ = 1.4 s) | 0.1 J design limit | ✅ PASS | 26% of limit · Road round 9 (A8-N03, R9X-07); the 2 τ top-up time is a Marine parameter-set value |

### Discharge — M10 IGBT (bleeder 2 × 8 × 22 k · active 5 × 470 Ω)

| Check | Value | Limit | Verdict | Note |
|---|---|---|---|---|
| Passive 1100→60 V, worst (R+5 %, C+10 %) | 89.6 s | 120 s service rule | ✅ PASS | 75% of limit · nominal 77.6 s |
| Bleeder V on the worst-tolerance resistor @1100 V | 150 V | 200 V working (2512) | ✅ PASS | 75% of limit |
| Bleeder W/resistor @1100 V (R−5 %) | 0.9 W | 2 W | ✅ PASS | 45% of limit · standing loss 14 W |
| Active + passive 1100→60 V, worst corner | 2.33 s | 5 s (IEC 61800-5-1 accessible-part rule) | ✅ PASS | 47% of limit |
| Energy per 10 W wirewound (C+10 %) | 40.3 J | 100 J single-pulse | ✅ PASS | 40% of limit · firmware ≤ 3 discharges / 5 min |
| V per wirewound | 220 V | ≥350 V axial class | ✅ PASS | 63% of limit |
| QDIS switch | 0.47 A pk at 1100 V | ≥ 1700 V class switch | ✅ PASS | fully enhanced, no linear region; gate through the kept 1.5 k/10 k divider, now 11.6–16.3 V from the UCC14141-Q1 (Road A.12; low end set by the VOW3120's guaranteed V_OH ≥ V_CC − 4 V) — same bias module, already rated ≥ 1150 V DC |
| QDIS stuck ON with the battery connected | 515 W continuous (103 W per resistor) | not survivable by 10 W parts | 🟡 WARN | bounded as on the Road (F23): fire only with the DC breaker reported OPEN; now detected at the next contactor opening → latched no-re-energise DTC + contactor-open request (Road round 14/A.13, replaces the earlier precharge-only check); no-flame per the TT/Welwyn SQP10 statement (will not burn or emit incandescent particles under any condition of applied temperature or overload) holds at any overload, so it covers this power without the Road A6-R11 70–100 W qualification window; fail-open TIME at this power is a QP-MA-05 characterisation, not a release gate (Road gate ㉖) |
| FW-16 self-test residual energy (read < 3 V, or QDIS for 2 τ from < 60 V) | ≤ 24 mJ (read) · ≤ 15 mJ (QDIS 2 τ = 1.64 s) | 0.1 J design limit | ✅ PASS | 24% of limit · Road round 9 (A8-N03, R9X-07); the 2 τ top-up time is a Marine parameter-set value |
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

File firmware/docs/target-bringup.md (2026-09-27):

# Target bring-up checklist (silicon / RM / RTD / HIL / EOL)

This is the one list of what the host build cannot prove. Every open item of the firmware is here and
nowhere else (round 17): each row names what must be read in the S32K39 reference manual (RM) or bound
against the installed RTD / S32 Config Tools project, or measured on silicon, HIL or at EOL; the check that
closes it; and what holds the image closed until then. Contract decisions are in
`docs/firmware-contract.md` (§10c lists them); this page holds only what needs the hardware.
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

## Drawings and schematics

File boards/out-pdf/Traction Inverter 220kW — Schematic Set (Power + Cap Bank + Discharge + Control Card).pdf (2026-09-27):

# DC-INPUT / ENTRY

DC-INPUT / EMI-Y | DC-INPUT / HVIL

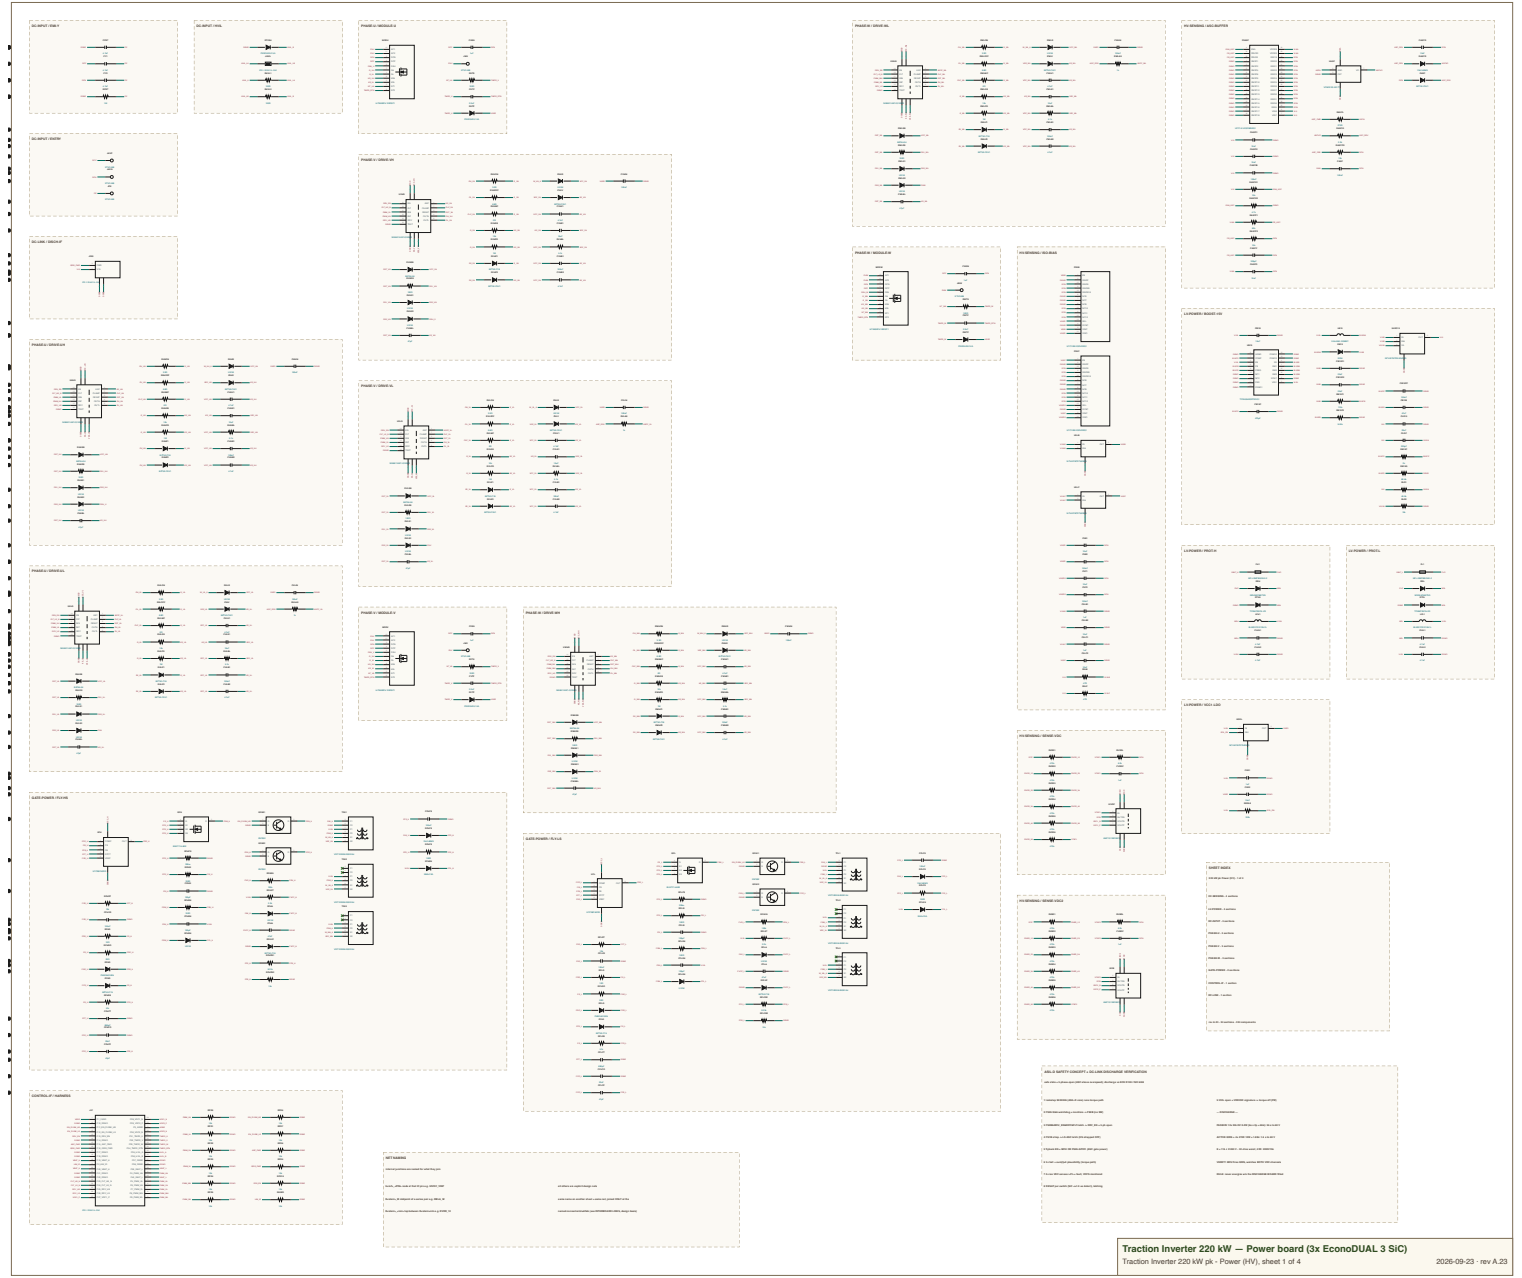
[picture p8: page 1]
SHEET INDEX; PHASE-U - 3 sections; PHASE-V - 3 sections; PHASE-W - 3 sections; NET NAMING; --- DISCHARGE ---; PASSIVE 12x 22k 2512-2W (6s x 2p = 66k): 56 s to 60 V; E = 116 J @850 V - 32 J/res worst; 4XX: 220R/15k; PHASE-U / MODULE-U; PHASE-V / MODULE-V; PHASE-W / MODULE-W; LV-POWER / PROT-H; LV-POWER / PROT-L; JHVN; STUD-M8; JHVP; JPE; STUD-M6; CPET; RPET; DTVSH; PESD5V0U1UA; JHVIL; IPL1-102-01-L-S-K; RHVL1; RHVL2; CMD; JDIS; IPL1-104-01-L-S-K; DCN; DCP; DSH; KSH; KSL; MODU; HCS600FH120D3C1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

PHASE-W / DRIVE-WL

HV-SENSING / ASC-BUFFER

PHASE-V / DRIVE-VH

DC-LINK / DISCH-IF

HV-SENSING / ISO-BIAS

LV-POWER / BOOST-15V

PHASE-U / DRIVE-UH

PHASE-V / DRIVE-VL

PHASE-U / DRIVE-UL

PHASE-W / DRIVE-WH

LV-POWER / VCC1-LDO

HV-SENSING / SENSE-VDC

GATE-POWER / FLY-HS

GATE-POWER / FLY-LS

220 kW pk Power (HV) - 1 of 4

HV-SENSING - 4 sections

HV-SENSING / SENSE-VDC2

LV-POWER - 4 sections

DC-INPUT - 3 sections

GATE-POWER - 2 sections

CONTROL-IF - 1 section

DC-LINK - 1 section

rev A.23 - 24 sections - 324 components

ASIL-D SAFETY CONCEPT + DC-LINK DISCHARGE VERIFICATION

safe state = 3-phase-open (ASC above overspeed); discharge vs ECE R100 / ISO 6469

CONTROL-IF / HARNESS

1 lockstep S32K396 (ASIL-D core) runs torque path

9 HVIL open = VDDIO/2 signature -> torque off (FW)

2 FS26 Q&A watchdog + monitors -> FS0B (no SW)

3 FS0B&MCU_EN&RDY&FLT-latch -> DRV_EN = 3-ph open

4 FS1B strap -> LS ASC latch (HS strapped OFF)

ACTIVE QDIS + 4x 470R 10W = 1.88k: 1.6 s to 60 V

5 flyback EN = MCU OR FS26-GPIO1 (ASC gate power)

6 3x hall + sum(I)=0 plausibility (torque path)

VERIFY: MCU fires QDIS, watches BOTH VDC channels

internal junctions are named for what they join

7 2x iso VDC senses >5% = fault, VOFS monitored

RULE: never energize w/o the DISCHARGE BOARD fitted

U<ref>_<PIN> node at that IC pin e.g. UIVDC_VINP

all others are explicit design nets

8 DESAT per switch (SiC <=1.9 us detect), latching

R<stem>_M midpoint of a series pair e.g. RBLA_M

same name on another sheet = same net, joined ONLY at the

R<stem>_<nm> tap between R<stem>n/m e.g. RVDD_12

named connector/stud/tab (see INTERBOARD LINKS, design basis)

Traction Inverter 220 kW — Power board (3x EconoDUAL 3 SiC)

### 220 kW pk Cap bank (HV, busbar) - 2 of 4 · rev A.23 · 2 sections · 26 components

NET NAMING: U<ref>_<PIN> = node at that IC pin · R<stem>_M = series-pair midpoint · R<stem>_<nm> = tap between R<stem>n/m · all others are explicit design nets · same name on another sheet = same net, joined only at the named connector/stud/tab

CAP-BANK / BUS-STUDS | CAP-BANK / CAN-ARRAY

JCBDN

STUD-M6

JCBDP

STUD-M6

JCBEN

STUD-M8

JCBEP

STUD-M8
JCBUN

TAB-M6

JCBUP

TAB-M6

JCBVN

TAB-M6

JCBVP

TAB-M6

JCBWN

TAB-M6

JCBWP

TAB-M6

CDC1

20uF
CDC10

20uF
CDC11

20uF
CDC12

20uF
CDC13

20uF
CDC14

20uF
CDC15

20uF
CDC16

20uF

CDC2

20uF
CDC3

20uF
CDC4

20uF
CDC5

20uF
CDC6

20uF
CDC7

20uF
CDC8

20uF

CDC9

20uF

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
DCP | DCN
DCP | DCN
DCP | DCN
DCP | DCN
DCP | DCN
DCP | DCN
DCP | DCN
DCP | DCN
DCP | DCN
DCP | DCN
DCP | DCN
DCP | DCN
DCP | DCN
DCP | DCN
DCP | DCN
DCP | DCN

# rter — Cap bank (busbar assembly, 320 uF)

220 kW pk - Cap bank (HV, busbar), sheet 2 of 4 | 2026-09-23 · rev A.23

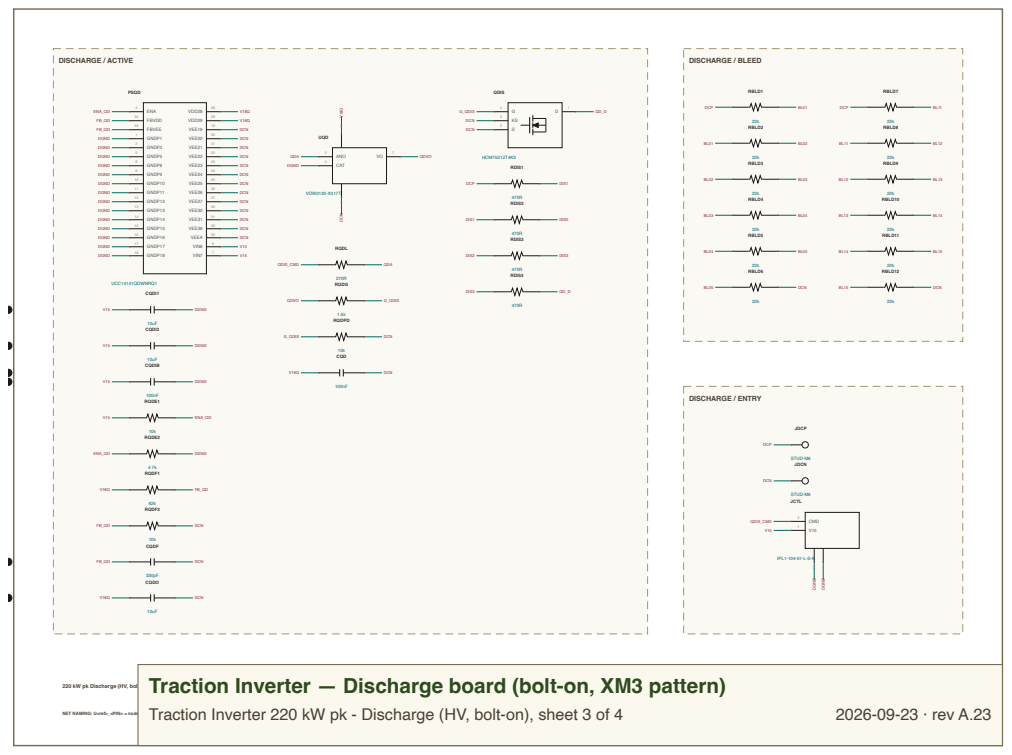
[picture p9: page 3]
DISCHARGE / ENTRY; DISCHARGE / ACTIVE; DISCHARGE / BLEED; CMD; JCTL; IPL1-104-01-L-S-K; JDCN; STUD-M6; JDCP; RBLD1; RBLD10; RBLD11; RBLD12; RBLD2; RBLD3; RBLD4; RBLD5; RBLD6; RBLD7; RBLD8; RBLD9; ENA; FBVDD; FBVEE; GNDP1; GNDP2; GNDP5; GNDP8; GNDP9; GNDP10; GNDP11; GNDP12; GNDP13; GNDP14; GNDP15; GNDP16; GNDP17; GNDP18; VDD28; VDD29; VEE19; VEE20; VEE21; VEE22; VEE23; VEE24; VEE25; VEE26; VEE27; VEE30; VEE31; VEE36; VEEA; VIN6; VIN7; PSQD; UCC14141QDWNRQ1; QDIS; ANO; HCM75S12T4K3; CAT; UQD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

Traction Inverter — Discharge board (bolt-on, XM3 pattern)

220 kW pk Discharge (HV, bolt-on) - 3 of 4 · rev A.23 · 3 sections · 35 components

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

CONTROL / MCU | CONTROL / SWD-BOOT
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

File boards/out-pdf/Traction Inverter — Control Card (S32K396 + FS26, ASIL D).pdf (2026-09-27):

CONTROL / MCU | CONTROL / SWD-BOOT

# SBC / FS26

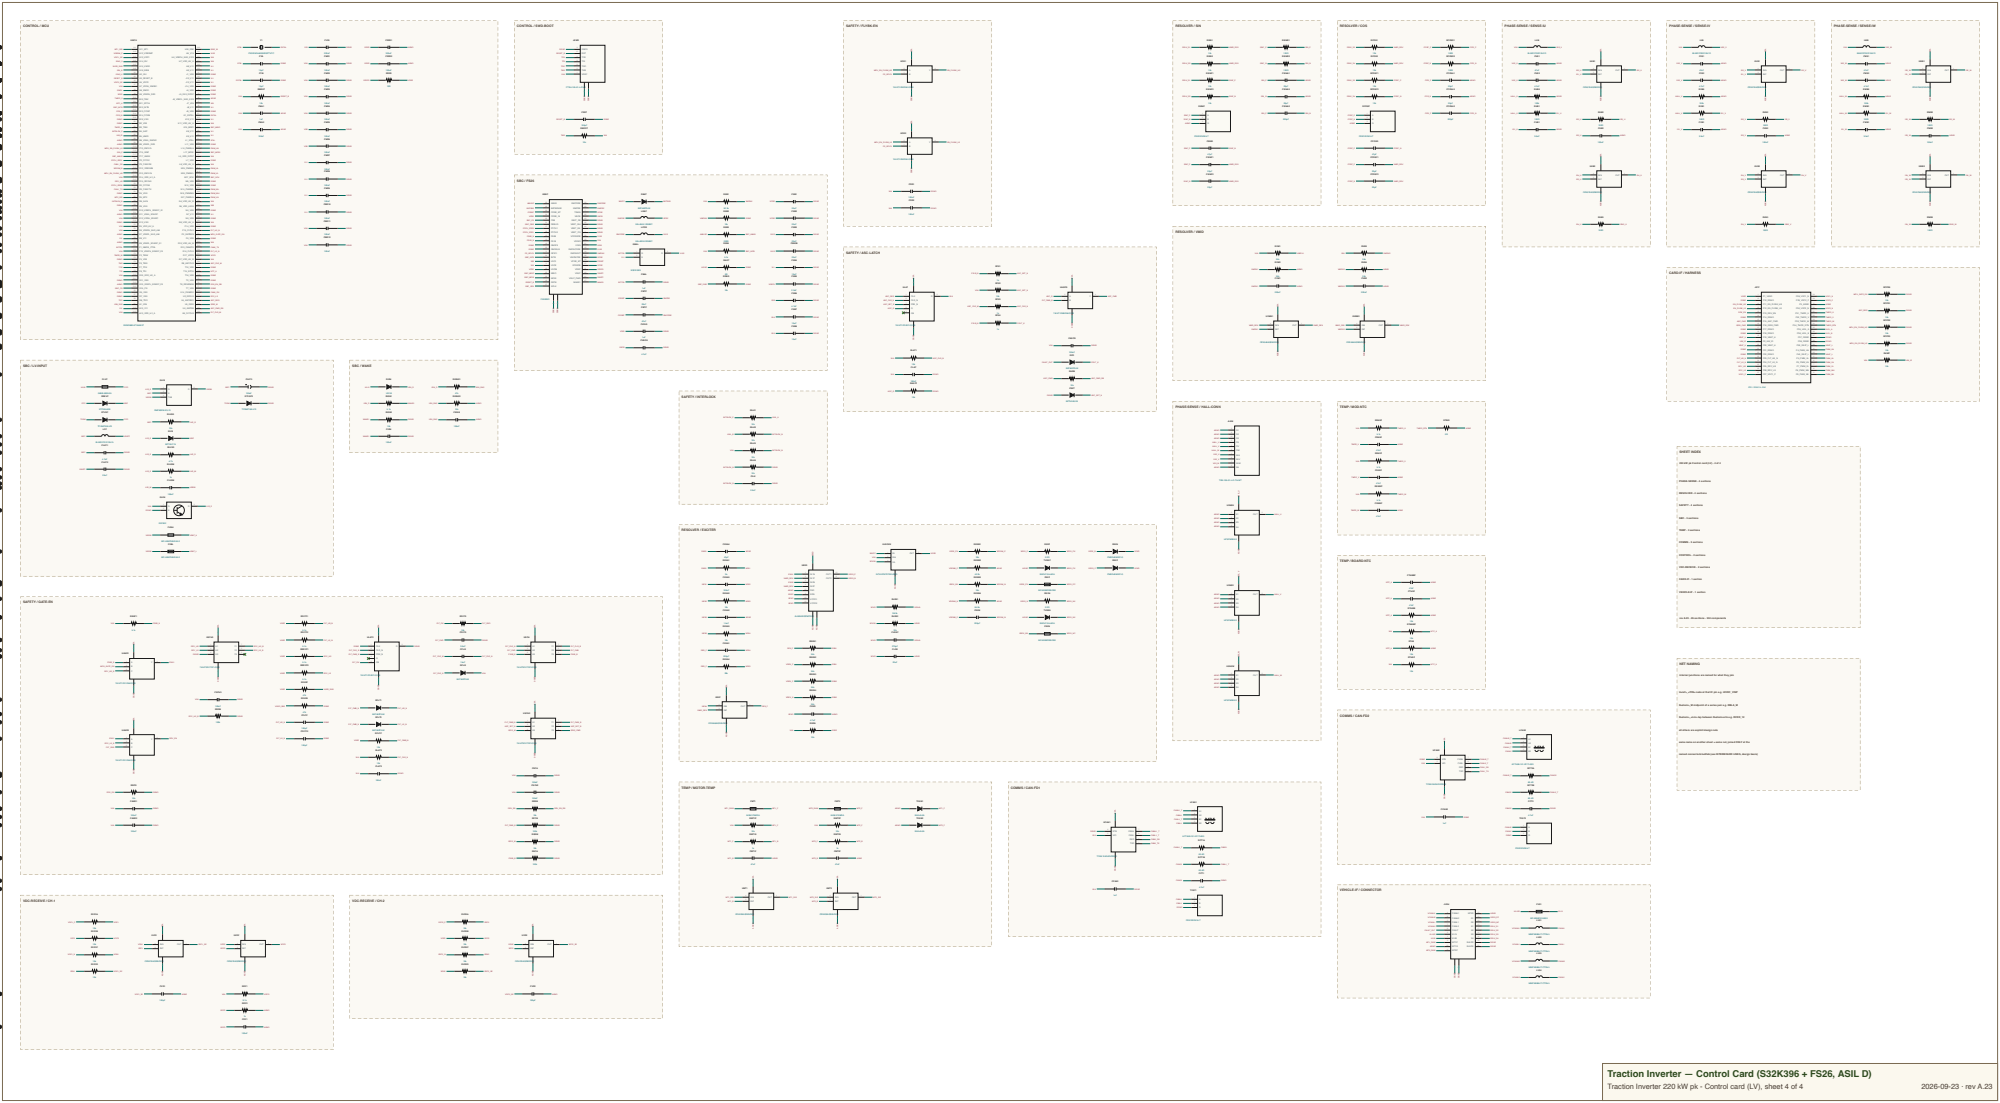
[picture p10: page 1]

PHASE-SENSE / HALL-CONN

220 kW pk Control card (LV) - 4 of 4

internal junctions are named for what they join

U<ref>_<PIN> node at that IC pin e.g. UIVDC_VINP

R<stem>_M midpoint of a series pair e.g. RBLA_M

R<stem>_<nm> tap between R<stem>n/m e.g. RVDD_12

all others are explicit design nets

same name on another sheet = same net, joined ONLY at the

named connector/stud/tab (see INTERBOARD LINKS, design basis)

Traction Inverter — Control Card (S32K396 + FS26, ASIL D)

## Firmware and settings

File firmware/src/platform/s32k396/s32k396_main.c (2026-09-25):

/* s32k396_main.c — reset entry, interrupt binding and the background loop (S32K396, lockstep
 * Cortex-M7 pair). Order follows §9 step 1: clocks, time base, every output at its safe level with
 * ASC_CLR_N high before any output buffer is enabled, then the application (which locks the
 * eFlexPWM fault configuration before anything can modulate).
 *
 * Interrupts (NVIC priority, 0 = highest):
 *   0  eFlexPWM_1 fault (FFLAG)        -> app_fault_isr_entry()   FW-15 step 1, FW-06, FW-05
 *   1  eDMA major loop, SDADC1/2/3      -> s32k_sdadc_dma_irq(ch)  per-channel completion (round 16)
 *   2  BCTU end of list (phase currents)-> app_isr_current()       2 x f_sw
 *   4  STM_0 channel 0 (1 ms)           -> app_task_1ms()
 *   5  FlexCAN0/1                        -> RTD ISR -> s32k_can_callback()
 * app_idle() runs in the background loop (NVM queue only). */
#include "app.h"
#include "s32k396.h"
#include "ti_params.h"

#ifdef TI_RTD_AVAILABLE
#include "Clock_Ip.h" /* TODO(RTD): the IP drivers, the Config Tools symbols and the device-header IRQ numbers below */
#include "Fccu_Ip.h"
#include "IntCtrl_Ip.h"
#include "Siul2_Port_Ip.h"
extern const Clock_Ip_ClockConfigType Clock_Ip_aClockConfig[];
extern const IntCtrl_Ip_CtrlConfigType IntCtrlConfig_0;
extern const Siul2_Port_Ip_PinSettingsConfig g_pin_mux_InitConfigArr0[];
extern const Fccu_Ip_ConfigType Fccu_Ip_Config;
#define TI_PIN_COUNT NUM_OF_CONFIGURED_PINS0
/* IRQ numbers of the S32K39 device header */
#define TI_IRQ_PWM1_FAULT PWM1_FAULT_IRQn
#define TI_IRQ_BCTU BCTU_IRQn
#define TI_IRQ_SDADC_EXC DMATCD_SDADC1_IRQn /* the eDMA channel interrupt of each SDADC's channel */
#define TI_IRQ_SDADC_SIN DMATCD_SDADC2_IRQn
#define TI_IRQ_SDADC_COS DMATCD_SDADC3_IRQn
#define TI_IRQ_STM0 STM0_IRQn
#endif

#ifndef TI_RTD_AVAILABLE
ti_shadow_t g_ti_shadow; /* register shadow of the host syntax-check build */
#endif

/* ---------------- interrupt handlers ---------------- */
static void isr_pwm_fault(void) { app_fault_isr_entry(); /* FFLAG stays set until FW-15 step 4 */ }

static void isr_sd_exc(void) { s32k_sdadc_dma_irq(HAL_SD_EXC); }
static void isr_sd_sin(void) { s32k_sdadc_dma_irq(HAL_SD_SIN); }
static void isr_sd_cos(void) { s32k_sdadc_dma_irq(HAL_SD_COS); }

static void isr_current(void)
{
    app_isr_current(&g_app);
#ifdef TI_RTD_AVAILABLE
    /* TODO(RTD): clear the BCTU list-complete flag (Bctu_Ip_ClearStatusFlag or the ISR wrapper) */
#endif
}

static void isr_task(void)
{
#ifdef TI_RTD_AVAILABLE
    /* TODO(RTD): STM channel 0 flag clear and CMP += 1000 (the Stm_Ip ISR wrapper does both) */
#endif
    app_task_1ms(&g_app);
}

/* 64-bit device UID as the calibration serial (FW-20 binds the record to it). */
static void read_uid(uint8_t serial[8])
{
    for (uint32_t i = 0u; i < 8u; i++) {
        serial[i] = 0u; /* TODO(RTD/HW-RM): the S32K39 unique ID (UTEST / DCM); 0 fails calib_check */
    }
}

static void bind_interrupts(void)
{
#ifdef TI_RTD_AVAILABLE
    IntCtrl_Ip_Init(&IntCtrlConfig_0);
    IntCtrl_Ip_InstallHandler(TI_IRQ_PWM1_FAULT, isr_pwm_fault, NULL_PTR);
    IntCtrl_Ip_InstallHandler(TI_IRQ_SDADC_EXC, isr_sd_exc, NULL_PTR);
    IntCtrl_Ip_InstallHandler(TI_IRQ_SDADC_SIN, isr_sd_sin, NULL_PTR);
    IntCtrl_Ip_InstallHandler(TI_IRQ_SDADC_COS, isr_sd_cos, NULL_PTR);
    IntCtrl_Ip_InstallHandler(TI_IRQ_BCTU, isr_current, NULL_PTR);
    IntCtrl_Ip_InstallHandler(TI_IRQ_STM0, isr_task, NULL_PTR);
    IntCtrl_Ip_SetPriority(TI_IRQ_PWM1_FAULT, TI_PRIO_PWM_FAULT);
    IntCtrl_Ip_SetPriority(TI_IRQ_SDADC_EXC, TI_PRIO_SDADC);
    IntCtrl_Ip_SetPriority(TI_IRQ_SDADC_SIN, TI_PRIO_SDADC);
    IntCtrl_Ip_SetPriority(TI_IRQ_SDADC_COS, TI_PRIO_SDADC);
    IntCtrl_Ip_SetPriority(TI_IRQ_BCTU, TI_PRIO_CURRENT);
    IntCtrl_Ip_SetPriority(TI_IRQ_STM0, TI_PRIO_TASK);
    /* FlexCAN IRQs: priority TI_PRIO_CAN in IntCtrlConfig_0 */
    IntCtrl_Ip_EnableIrq(TI_IRQ_PWM1_FAULT);
    IntCtrl_Ip_EnableIrq(TI_IRQ_SDADC_EXC);
    IntCtrl_Ip_EnableIrq(TI_IRQ_SDADC_SIN);
    IntCtrl_Ip_EnableIrq(TI_IRQ_SDADC_COS);
    IntCtrl_Ip_EnableIrq(TI_IRQ_BCTU);
    IntCtrl_Ip_EnableIrq(TI_IRQ_STM0);
#else
    (void)isr_pwm_fault;
    (void)isr_sd_exc;
    (void)isr_sd_sin;
    (void)isr_sd_cos;
    (void)isr_current;
    (void)isr_task;
#endif
}

int main(void)
{
#ifdef TI_RTD_AVAILABLE
    /* TODO(RTD): Clock_Ip_Init(&Clock_Ip_aClockConfig[0]) — PLL, core, AIPS, eFlexPWM (TI_PWM_CLK_HZ),
     * SDADC and STM clocks. Fccu_Ip_Init(): lockstep (DCM) and ECC faults to FCCU_ERR0/1 (the FS26
     * ERRMON input). Siul2_Port_Ip_Init(): alternate functions only; GPIO outputs are enabled by
     * s32k_gpio_init() after their latches are written. */
    (void)Clock_Ip_Init(&Clock_Ip_aClockConfig[0]);
    (void)Siul2_Port_Ip_Init(TI_PIN_COUNT, g_pin_mux_InitConfigArr0);
    (void)Fccu_Ip_Init(&Fccu_Ip_Config);
#endif
    (void)s32k_timer_init();
    (void)s32k_gpio_init();
    uint8_t serial[8];
    read_uid(serial);
    app_init(&g_app, ti_params_active(), NULL, serial); /* NULL: calibration from NVM (FW-20) */
    bind_interrupts();
    for (;;) {
        app_idle(&g_app); /* NVM queue; everything else is interrupt driven */
    }
}

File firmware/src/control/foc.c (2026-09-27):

/* foc.c — current loop (runs in the PWM-synchronised ISR, twice per PWM period). */
#include "foc.h"

void foc_reset(foc_t *f)
{
    const bool guard = f->guard_trip;
    *f = (foc_t){0};
    f->guard_trip = guard;
    for (uint32_t i = 0u; i < 3u; i++) {
        f->duty[i] = 0.5f;
    }
}

void foc_clarke(const float iabc[3], float *ia, float *ib)
{
    *ia = ((2.0f * iabc[0]) - iabc[1] - iabc[2]) * (1.0f / 3.0f);
    *ib = (iabc[1] - iabc[2]) * (1.0f / TI_SQRT3);
}

void foc_park(float a, float b, float th, float *d, float *q)
{
    const float c = cosf(th);
    const float s = sinf(th);
    *d = (a * c) + (b * s);
    *q = (-a * s) + (b * c);
}

void foc_ipark(float d, float q, float th, float *a, float *b)
{
    const float c = cosf(th);
    const float s = sinf(th);
    *a = (d * c) - (q * s);
    *b = (d * s) + (q * c);
}

void foc_svpwm(float va, float vb, float vdc, float duty[3])
{
    const float v[3] = {va, (-0.5f * va) + (0.5f * TI_SQRT3 * vb), (-0.5f * va) - (0.5f * TI_SQRT3 * vb)};
    const float vmax = ti_maxf(v[0], ti_maxf(v[1], v[2]));
    const float vmin = ti_minf(v[0], ti_minf(v[1], v[2]));
    const float off = 0.5f * (vmax + vmin);
    for (uint32_t i = 0u; i < 3u; i++) {
        duty[i] = 0.5f + ((v[i] - off) / vdc);
    }
}

void foc_dt_comp(float duty[3], const float iabc[3], float dt_frac, float band_a)
{
    for (uint32_t i = 0u; i < 3u; i++) {
        duty[i] += ti_clampf(iabc[i] / band_a, -1.0f, 1.0f) * dt_frac;
    }
}

static bool all_finite(const float *x, uint32_t n)
{
    bool ok = true;
    for (uint32_t i = 0u; i < n; i++) {
        ok = ok && ti_finite(x[i]);
    }
    return ok;
}

/* conditional integration: an axis integrates unless its output is limited AND the error would
 * push it further into the limit (a back-calculation that rewrites the integrator whenever the
 * proportional term alone exceeds the limit leaves a long negative tail) */
static float integrate(float xi, float e, float v, float v_u, float ki_ts, float lim)
{
    const bool limited = (v != v_u);
    if (!limited || ((e * v_u) < 0.0f)) {
        xi += ki_ts * e;
    }
    return ti_clampf(xi, -lim, lim);
}

static void pi_axes(foc_t *f, float ed, float eq, float ffd, float ffq, float kp_d, float kp_q, const gain_set_t *g)
{
    const float vd_u = (kp_d * ed) + f->xi_d + ffd;
    const float vq_u = (kp_q * eq) + f->xi_q + ffq;
    f->vd = ti_clampf(vd_u, -f->vmax, f->vmax);
    const float vq_lim = sqrtf(ti_maxf((f->vmax * f->vmax) - (f->vd * f->vd), 0.0f));
    f->vq = ti_clampf(vq_u, -vq_lim, vq_lim);
    f->sat = (f->vd != vd_u) || (f->vq != vq_u);
    const float ki_ts = g->ki_v_per_as * g->ts_s;
    f->xi_d = integrate(f->xi_d, ed, f->vd, vd_u, ki_ts, f->vmax);
    f->xi_q = integrate(f->xi_q, eq, f->vq, vq_u, ki_ts, f->vmax);
}

bool foc_step(foc_t *f, const float iabc[3], float theta_e, float omega_e, float vdc, const motor_t *m,
              const gain_set_t *g, const ti_params_t *p)
{
    const float in[4] = {theta_e, omega_e, f->id_ref, f->iq_ref};
    if (!all_finite(iabc, 3u) || !all_finite(in, 4u) || !ti_finite(vdc) || (vdc <= 1.0f)) {
        f->guard_trip = true;
        return false;
    }
    float ia;
    float ib;
    foc_clarke(iabc, &ia, &ib);
    foc_park(ia, ib, theta_e, &f->id, &f->iq);
    f->vmax = p->cal_mod_index_max * vdc * (1.0f / TI_SQRT3);
    /* round 23 (FW-45): the speed voltages from the maps' flux linkages (the apparent inductance), and per axis the
     * proportional gain scaled by the differential inductance at the measured current over the unsaturated one, in
     * [FOC_KP_FLOOR, 1]: the crossover gains.c placed stays put as the machine saturates (pole-zero cancellation: the
     * integral gain R wc needs no scaling, the zero R / L follows the pole). Exactly the fixed gain for a flat map. */
    float dd;
    float dq;
    const float pd = motor_sat(m->ld_map_h, ti_absf(f->id), m->i_map_a, &dd);
    const float pq = motor_sat(m->lq_map_h, ti_absf(f->iq), m->i_map_a, &dq);
    const float ffd = -omega_e * (m->lq_h * pq) * f->iq;
    const float ffq = omega_e * (((m->ld_h * pd) * f->id) + m->psi_wb);
    pi_axes(f, f->id_ref - f->id, f->iq_ref - f->iq, ffd, ffq, g->kp_v_per_a * ti_clampf(dd, FOC_KP_FLOOR, 1.0f),
            g->kp_v_per_a * ti_clampf(dq, FOC_KP_FLOOR, 1.0f), g);
    float va;
    float vb;
    foc_ipark(f->vd, f->vq, theta_e + (omega_e * g->delay_s), &va, &vb);
    float d[3];
    foc_svpwm(va, vb, vdc, d);
    foc_dt_comp(d, iabc, (float)p->dead_time_ns * 1.0e-9f * (float)g->fsw_hz, p->cal_dtcomp_band_a);
    for (uint32_t i = 0u; i < 3u; i++) {
        d[i] = ti_clampf(d[i], 0.0f, 1.0f);
    }
    const float st[2] = {f->xi_d, f->xi_q};
    if (!all_finite(d, 3u) || !all_finite(st, 2u)) {
        f->guard_trip = true;
        return false;
    }
    for (uint32_t i = 0u; i < 3u; i++) {
        f->duty[i] = d[i];
    }
    return true;
}

float foc_omega_model(const foc_t *f, const motor_t *m, bool *valid)
{
    float dd;
    const float flux = ((m->ld_h * motor_sat(m->ld_map_h, ti_absf(f->id), m->i_map_a, &dd)) * f->id) + m->psi_wb; /* FW-45 */
    *valid = !f->sat && (ti_absf(flux) > (0.2f * m->psi_wb));
    return *valid ? ((f->vq - (m->rs_ohm * f->iq)) / flux) : 0.0f;
}

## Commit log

2026-09-09 GEN-1 rev A.2: 220 kW / 800 V SiC traction inverter — schematic-complete
    Two-board set (Power HV + Control card LV) generated from tscircuit source:
    3x HIITIO HCS600FH120D3C1 (EconoDUAL 3), NSI6611A-Q1 gate drive, S32K396 +
    FS2633D ASIL-D control (NXP GEN3 architecture), active + passive discharge
    (1.9 s / 57 s to 60 V, on-sheet verification panel), hardware safety chain
    with latched low-side ASC.
    Pipeline: netlists -> sectioned KiCad-5 sheets -> independent geometric
    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
    [bom-control-card.csv, bom-power.csv, traction-card.sch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]
2026-09-09 Rev A.3: end-to-end verification campaign — 18 defects found & fixed, datasheet pack
    Three independent verification layers, all green at datasheet-real constants:
    - geometric pin-verify 1540/1540 (100%)
    - structural ERC audit (new erc-audit.mjs): 664 intent-level checks, 0 fail
    - numeric worst-case verification (new design-verify.mjs): 51 PASS / 3 WARN /
    0 FAIL at real corners (Vbus->850V, KL30 9-16V, R+/-5%, C+10%)
    Findings fixed (docs/verification-report.md, F1-F36): flyback CS scaling, FB
    reference mis-scaled for controller swap (supply could never start), missing
    VCC start path, five net-alias floating pins, Y-cap class at 850V, common-cause
    VDC sense bias, load-dump cap ratings, di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
    [bom-control-card.csv, bom-power.csv, traction-card.sch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]
2026-09-09 Split discharge onto a bolt-on board (XM3 pattern), 3-sheet set
    - boards/discharge.tsx: bleeder (2x5x27k) + active discharge (4x470R +
    HCM75S12T4K3, TLP152/QA01C default-OFF) on its own PCB across the cap
    bank; power board keeps JDIS header (V15/QDIS_CMD/2xGND) + CMD pulldown
    - pipeline: disch side threaded through pages/gen/verify/print/pdf/bom;
    sheet idents 1..3 of 3; disch title block carries "NEVER energize
    without this board fitted"; root sheet de-branded (X-IN-One -> Traction)
    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
    [bom-discharge.csv, bom-power.csv, traction-card.sch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]
2026-09-09 Add cap-bank busbar assembly sheet + explicit interboard links (4 sheets)
    - boards/capbank.tsx: the 16-can DC-link is its own laminated-busbar
    assembly (FR4 cannot carry the 340 A bus) with every terminal drawn:
    entry lugs, 3x module DC tab pairs, discharge-board studs
    - power board keeps only its DCP/DCN entry taps (Y-caps, HVIL, sense)
    - interboard links L1-L5 (harness, discharge 4-way, busbar, LEM, HVIL)
    documented in design-basis 10a + README table; erc-audit now asserts
    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
    [bom-capbank.csv, bom-power.csv, traction-capbank.sch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]
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2026-09-09 Rev A.4: answer external design review — 10 confirmed defects fixed (F37-F46)
    Every claim verified against primary datasheets before any edit; three
    claims rebutted with evidence (850V/0.1% divider corner, GEN3-exact
    resolver monitors, discharge math matches). Fixed:
    - F37 VGT12EEM secondary phasing: rectifier moved to pin 8 (dot); the
    drawn wiring was forward-mode ~35V into +22V-abs gates. Pins 6/7 NC'd
    (no internal winding). Aux (NF) was already correct.
    - F38 flyback drain clamp: SMBJ85A (forward every OFF interval, 94.4V
    min breakdown vs 80V FET) -> US1M + SMAJ13A winding clamp; drain
    <=60V at clamped load dump
    - F39 DESAT clamp: BAT64-04 series pair correctly oriented DESAT->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
    [bom-control-card.csv, bom-power.csv, traction-capbank.sch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]
2026-09-09 Rev A.4.1: second review round — 5 confirmed defects fixed (F47-F51)
    - F47 AMC1311 real pins 2=IN/3=SHTDN (both VDC channels had them
    swapped: analog inputs grounded, SHTDN on the divider tap)
    - F48 FS26 TRKIN is the VREF regulator's input supply -> VPRE
    (was grounded as an "unused tracker input"; VREF5 had no source)
    - F49 TPS55340 pin 5 is SYNC (7V abs), not a second VIN -> DGND
    - F50 FS26 caps to DS minimums: CVBOS 4.7uF, CSB6 4.7uF, CSB5 2.2uF
    (VREF COUT 1.1-3.3uF eff - third value found in the same audit)
    - F51 V15 protective post-regulator NCV4276C-ADJ 40V/0.4A: boost
    pass-through (24V jump start / ~33V clamped load dump) can no longer
    reach the QA01C 13.5-16.5V window; boo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
    [bom-control-card.csv, bom-power.csv, traction-capbank.sch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]
2026-09-09 Rev A.4.2: third review round — 6 confirmed defects fixed (F52-F57)
    - F52 FS26 buck passives to Table-106 selections: LCOR 2.2uH
    (CORE_LSEL_OTP=0x02; 4.7uH matched no listed value), V15S COUT
    2x22uF (~32uF eff vs 20-100 spec), CBTC 47nF, CBTP 22nF per
    CBOOT_PRE, VPRE COUT 2x22uF, CIN 22uF; effective-capacitance rows
    (bias/tol/temp derating) added to design-verify. VREF5 judged as a
    rail (CSB5+CMA1+CMA2 ~2.2uF eff, inside 1.1-3.3) per reviewer.
    - F53 ACT45B CAN chokes: real windings are pins 1-4 and 2-3 (TDK
    circuit diagram) - both ports had transceiver CANH coupled onto
    external CANL; remapped, ERC asserts end-to-end pairing
    - F54 ULDO15 completed: 220pF feed-forward across t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
    [bom-control-card.csv, bom-power.csv, traction-capbank.sch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]
2026-09-09 Rev A.4.3: fourth review round — LCOR reconciled, UB15 compensation (F58-F59)
    - F58: LCOR netlist value became 2.2uH in A.4.2 but the parts-db class
    MPN kept printing IND-4.7uH-2A on the sheet and BOM - an assembler
    would fit the old part. MPN/desc now carry 2.2uH + the OTP pairing;
    value, sheet, BOM and CORE_LSEL_OTP=0x02 agree end-to-end.
    - F59: TPS55340 COMP had only 10nF to ground (no zero; ~0deg screening
    phase margin in the CCM model). Series R3/C4 = 2k/100nF per TI
    8.2.1.2.11 + 470pF HF pole cap; RHPZ ~450kHz not limiting; measured
    Bode stays a bench gate.
    - Narrative corrections per review: CBOOT_PRE 100nF was legal (Rev 6.1
    allows 22-100nF; 22nF kept as typ) - F52 lo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
    [bom-control-card.csv, bom-power.csv, traction-capbank.sch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]
2026-09-09 bom-gen: print string-typed inductance values (Value column was empty for all inductors)
    [bom-control-card.csv, bom-power.csv]
2026-09-09 Add operating-point simulation layer (sim-verify.mjs, S1-S7)
    Numerical time/frequency-domain simulations of the drawn circuits at
    actual operating conditions - the fourth verification gate alongside
    pin-verify, erc-audit, design-verify:
    - S1 flyback cycle-by-cycle DCM at 9/12/16V: rail 21.3V (target 21.4),
    4ms settle, steady Ipk 1.82A vs 3.03A limit, drain peak <=42.3V vs
    80V with the A.4 clamp
    - S2 UB15 current-mode Bode with the A.4.3 RC network: fc 1.9-2.5kHz,
    PM 72-75deg (vs ~0deg before the compensation fix)
    - S3 DC-link ripple by SVPWM switching-state simulation: 11.9A/can at
    the 340A/30s peak vs 15.4A rating (7.6A continuous)
    - S4 junction thermal transient 120kW->220kW/30s->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
2026-09-09 Rev A.4.4: round five — bind class MPNs to real parts, pin FS26 OTP config
    No electrical change. Procurement closure of the review's remaining
    generic identifiers, each verified against its manufacturer datasheet:
    - LCOR -> Coilcraft XAL4020-222MEC (2.2uH molded, AEC-Q200; values
    read from the XAL4000 datasheet, now in docs/datasheets)
    - LB15 + LSBC -> XAL4040-103MEC (one 10uH line item for both; LSBC
    pairing with FPRE_OTP=450kHz documented per the FS26 DS)
    - PS5B/PS5C -> Murata MGJ2D150505SC (+5V output used) behind an
    explicit PO gate: verify reinforced-insulation characterization at
    850VDC working and the SIP-7 pin map before ordering
    - RECOM R15P05S evaluated and REJECTED duri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
    [bom-control-card.csv, bom-power.csv, traction-capbank.sch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]
2026-09-09 Rev A.5: end-to-end documentation refresh + 3 defects the audit caught
    Docs (every file rewritten to the released state, history kept as
    labeled evidence):
    - README: five stacked review paragraphs consolidated into one campaign
    table (F1-F62); new Simulation section with the S1-S7 results table
    and all five SVG plots; badges/stats/mermaids/DFM rows refreshed
    (UCC28C40, four-assembly build flow, 770669-1, sim badge, rev A.5)
    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
    [bom-control-card.csv, bom-discharge.csv, bom-power.csv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]
2026-09-09 IGBT drop-in variant: HCG600FH120D3E1EA on the same D3 pads (BOM variant)
    Same boards, same layout, same pin map (verified from the HCG DS p.8
    circuit diagram: identical 11-pin EconoDUAL-3 assignment to the SiC
    part). The whole variant is two value swaps on existing pads plus
    firmware constants:
    - MODx -> HCG600FH120D3E1EA (VCEsat 1.50/1.82V, Eon+Eoff 143.7mJ hot,
    Qg 4.36uC, Isc 1800A, Tvjop 150C, NTC B3375; DS in docs/datasheets)
    - RxDS 100R -> 4.7k: DESAT trip 8.1 -> 5.75V (3.2x VCEsat hot)
    - CxBL 47p -> 150p: blanking ~2.8us vs 10us-class SC withstand
    - gate rails UNCHANGED (+15.6/-5.1): DS characterizes at +/-15V,
    VGE(th) 5.0-6.2V is high, NSI6611 Miller clamp holds off-state
    - firm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
    [bom-capbank-igbt.csv, bom-control-card-igbt.csv, bom-discharge-igbt.csv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]
2026-09-09 Docs audit pass 2: design-basis header to A.5, IGBT variant in DFM + cost rollup, BOM cross-links
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2026-09-09 Dual-version docs end to end: SiC and IGBT first-class everywhere
    - NEW docs/variants.md: complete SiC-vs-IGBT comparison — ratings,
    performance, per-switch losses, thermal (incl. S4 transient 89C vs
    110C at the 220kW/30s peak), switching/acoustics, SC protection,
    gate-power, the 3-line hardware delta, BOM/unit-cost/pricing for
    both, when-to-choose, variant-specific open items
    - Simulations run both builds: S4 dual-series thermal transient,
    S1b IGBT gate-bank load @6kHz, S9 already dual; 23 PASS/2 WARN/0 FAIL
    - README: silicon badge dual, ratings rows (fsw + efficiency per
    build), Key-silicon dual module row, BOM section now a two-build
    table (BOM / ex-works / price for each)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
2026-09-22 Rev A.6: review round 6 response, one platform / four SKUs, N7-N9
    External review round 6 (46 findings, R-F01..R-F46) was verified finding by
    finding and classified in docs/review-A6-disposition.md (+ .csv): 20
    Confirmed, 9 Already Fixed, 6 Firmware Handled, 5 Not Applicable,
    6 Improvement Recommended. Repo findings F63-F76 are in the verification log.
    Hardware (+Rs31/unit, all SKUs unless noted):
    - SiC gate 3.3/6.8 ohm; IGBT 1.0/1.0 ohm + 82 pF DESAT blanking (HCG600
    short-circuit rating is 6 us, not 10)
    - gate-power flyback start: 2.2 k + 47 uF VDD + 18 V VDD zener (UCC28C40 has
    0.4 V UVLO hysteresis and no clamp); IGBT builds use RT 8.2 k for margin
    - fault latch: 10 k / 3.3 nF delay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
    [bom-capbank-igbt4.csv, bom-capbank-sic4.csv, bom-control-card-igbt4.csv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]
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2026-09-23 Rev A.7: review round 7 response (RR01-RR10, A6-R01-R14) + cross-check
    Two independent rechecks of c963794 were verified finding by finding and
    classified in docs/review-A7-disposition.md (+ .csv): 17 confirmed and fixed,
    1 spec gap closed, 3 firmware handled, 3 already-tracked release gates. Two
    further defects were self-found (N10, N11).
    Safety logic (control card):
    - 74LVC3G17-Q100 Schmitt buffer between the RC timing nodes (clear one-shot,
    soft-off delay) and the LVC inputs they drove at 14,000-63,500 ns/V. The
    FS0B line goes through it too; a 100 k pull-down makes a dead buffer
    force DRV_EN low.
    - FS0B/FS1B pull-ups 1 k -> 5.1 k (FS1B inside its 2 mA V_OL point).
    - FAULT_OUT made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
    [bom-capbank-igbt4.csv, bom-capbank-sic4.csv, bom-control-card-igbt.csv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]
2026-09-23 Rev A.8: review round 8 response (R7-01..07, A7-N01..05) + cross-check
    Review round 8 on 2ac42ed, every finding verified and classified in
    docs/review-A8-disposition.md (+ .csv); findings log F90-F105.
    Hardware (+Rs18/unit: SiC Rs71,040, IGBT Rs45,540):
    - UASCG 74LVC1G08-Q100: ASC_CMD = ASC latch AND no driver FLT, so a
    latched DESAT drops ASC on every path, FS1B included (R7-01/A7-N01;
    NSI6611 DS Fig. 8.11 read directly)
    - USCH2 74LVC3G17-Q100 buffers both latch presets and drives QDIS_CMD;
    FLT diode-OR now BAT46 for the Schmitt threshold (R7-02, R7-03, N12)
    - ZSET BZT52-B5V6 to ground replaces the clamp into V5A; RENP2 removed
    (A7-N04; B5V6 keeps a 35 V load dump under the 6.5 V V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
    [bom-control-card-igbt.csv, bom-control-card-igbt4.csv, bom-control-card-sic4.csv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]
2026-09-23 Rev A.9: review round 9 response (A8-01..03, A8-N01..N03) + cross-check
    Review round 9 on 0da9014, every finding verified and classified in
    docs/review-A9-disposition.md (+ .csv, 34 items); findings log F106-F119.
    Hardware (+Rs29/unit: SiC Rs71,069, IGBT Rs45,569):
    - PSASC/PSQD bound to the real QA01C-18 sheet (+18/-3 V; F61 had read
    the base QA01C, +20/-4 V): envelope 16.9-20.9 V, ASC entry 7.52 us,
    FW-06 end-point 906 V; discharge gate divider RQDG 1.5k (Vgs 13.4-18.1 V)
    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
    [bom-control-card-igbt.csv, bom-control-card-igbt4.csv, bom-control-card-sic4.csv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]
2026-09-23 Rev A.10: schematic rechecks of A.9 (A9-S01, S9-01, S9-02)
    Two schematic-only rechecks of 7235337 kept every A.9 correction;
    dispositioned in docs/review-A10-disposition.md (+ .csv); F120-F122.
    - RDY_HS/RDY_LS now reach UAND1/UAND2 through a third 74LVC3G17-Q100
    (USCH3, RRDB dead-state pull-down): the open-drain lines rose at
    ~20-100 ns/V against the 74LVC1G11's 10 ns/V limit (A9-S01; reverses
    the round-7/8 "state-benign" rejection)
    - RASCG = ROHM ESR03EZPF2201 (0.27 W at 85 C): it carries up to 0.12 W
    for as long as ASC is held; 2.2 k kept for the ASC timing (S9-01)
    - discharge sheet note 66k bleeder; gate divider stated as 13.3-18.2 V
    (a divider, not a clamp); A9 disposition quo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
    [bom-control-card-igbt.csv, bom-control-card-igbt4.csv, bom-control-card-sic4.csv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]
2026-09-24 Round 11: closure rechecks of A.10 (docs only)
    Two schematic-only rechecks of 3304b39 closed A9-S01, S9-01 and S9-02 and
    asked for no circuit change. Rev stays A.10; no hardware, BOM or netlist
    change.
    - review-A10-disposition.md/.csv: round-11 closure section, verified
    against the datasheets (USCH3 pins, RRDB dead-state level <= 0.32 V,
    enable chain, RASCG, bleeder, QDIS divider)
    - Leftover "13.4-18.1 V" wording corrected to 13.3-18.2 V with 1 %
    resistors: ERC label, design-basis 11i, F107 register row
    - dfm.md 4: ESR03 terminal-temperature layout rule (RASCG <= 138 C,
    RFS4 <= 132 C at their worst loads)
    - README and design-basis 11j: round-11 rows
    ERC 891/0; design-verify 118 PAS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
    [review-A10-disposition.csv]
2026-09-24 Rev A.11: review round 12 response (R1-F01..F28, R2-F01..F35) + datasheet archive
    Two whole-system reviews of 4544715 (28 + 35 findings), dispositioned line by
    line in docs/review-A11-disposition.md (+ CSV). Twelve real findings fixed
    (F123-F134); the rest are tracked gates, firmware-owned, wording or out of the
    schematic release's scope. No power-stage, capacitor or topology change.
    Hardware / contract:
    - SS6 release rule (a) is an energy inequality: winding energy 1.5*L*I^2 plus the
    back-EMF work during the decay, closed-form screen while E < V0, diode-bridge
    simulation otherwise; screening rows (WARN) per SKU
    - Resolver exciter rewired as a textbook MFB (1.5 nF / 220 pF): the drawn n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
    [bom-control-card-igbt.csv, bom-control-card-igbt4.csv, bom-control-card-sic4.csv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]
2026-09-24 Rev A.12: round 13 rechecks (F135-F139), pin freeze (F140), barrier + orderability closure (F141-F142), Marine A.12, firmware
    - Rechecks of 30ae0a2: §6 winding-energy rule at every speed; resolver 12 k series + 220 pF C_AAF
    (injection 2.92 mA with the MCU unpowered); verifier counts distinct assemblies; TPS55340-Q1 real
    ratings (38/40 V); NCV4276C thermal on the datasheet pad.
    - MCU pin freeze: all 289 S32K396 balls bound from SPF-91122 rev C anchored on the DS supply balls
    (calculations/mcu-ballmap.json, docs/mcu-pin-manifest.md); seven port corrections; FS26 pins verified;
    ERC pin-freeze lock.
    - Barrier closure: VOW3120-X017T optos and UCC14141-Q1 biases (shared IsoBias18 cell, si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
    [bom-capbank-igbt4.csv, bom-capbank-sic4.csv, bom-control-card-igbt.csv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]
2026-09-24 Rev A.13: round 14 — three reviews of cfd35a7 (F143-F158): MCU map vs NXP netlist, fail-closed firmware, terminal-fault protection
    - Pin freeze reopened and closed: H5 is V15 (1.5 V, was on VREF5) and J7 is V25 (regulator output,
    was grounded); whole map re-derived against NXP's GEN3 net report NET-91122_C (U513, 244 balls) —
    every supply ball and 164/165 port names agree; HW_ID/NTC_A/MT2_SIG/ASC_REQ moved to netlist-confirmed
    balls (B5/T15/D5/U4); KiCad symbol numbered by physical ball, mutation-tested; CNMOS 1 nF.
    - Firmware (214 tests / 1622 checks, ASan/UBSan, target-check): DESAT hold for every caller, 64-bit
    monotonic clock, keep_hv from rule (b) reliance at any speed, IMCR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
    [bom-control-card-igbt.csv, bom-control-card-igbt4.csv, bom-control-card-sic4.csv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]
2026-09-25 Rev A.14: round 15 — three rechecks of a8c75eb (F159-F164): exciter TVS behind the PTC, native-KiCad variant, PTC 1812, ADC class, contactor loss
    - Exciter terminal-fault protection: the round-14 TVS sat on the connector node (fault current bypassed
    the PTC) — TVSEP/TVSEN moved to the protected node, RSXP/RSXN 2.2 R, monitor tap on the protected node,
    ERC graph-cut lock; PTC MF-MSMF020/33X in 1812 (hot hold 0.09 A at 85 C); verifier rows for the PTC-in-path
    currents, TVS energy, VEXD-absent back-drive, negative fault, amplitude at the resolver; gate 28 widened.
    - KiCad deliverables: kicad5/traction-native/ (un-mirrored library, same sheets, own zip) beside the
    EasyEDA-import vari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
    [bom-control-card-igbt.csv, bom-control-card-igbt4.csv, bom-control-card-sic4.csv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]
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2026-09-25 Rev A.16: round 17 — gap closure (F174-F189) + round 16 rev A.15 (F167-F173): every gap closed, upgraded or numbered
    Round 16 (rev A.15, three rechecks of 32214be): exciter MFB gain 24 k -> 28 k with the amplitude
    planes (setpoint 7.2 V pp at the monitor), unidirectional exciter TVS, /33X hold 0.07 A, firmware
    acquisition contracts (phase triplets, resolver frame age, coherent SDADC frames); BOM furnished
    (spec-class capacitors, drawn-size gate in bom-gen, last placeholders bound with archived sheets).
    Round 17 (rev A.16, "close all gaps" / "feel free to upgrade"):
    - Hardware: DEXP/DEXN PMEG4050EP-Q rated back-drive diversion (closes the ALM2402 OPEN row);
    exciter TVS -> SMDJ8.5A-HRA (3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
    [bom-control-card-igbt.csv, bom-control-card-igbt4.csv, bom-control-card-sic4.csv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]
2026-09-25 Rev A.17: round 18 — three rechecks of 4425af9 (F190-F198): diversion diodes on the amplifier node (loop passes RSX), diode cell cathode = pin 1 on all 35 diodes, exciter TVS/PTC rows at worst corner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
    [bom-control-card-igbt.csv, bom-control-card-igbt4.csv, bom-control-card-sic4.csv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]
2026-09-26 Rev A.18: round 19 — three rechecks of e315bf1 (F199-F204): PTC-current row at every permitted voltage (IR-16 0.08/0.14/0.37/0.26 Ω), ≥8 A TVS energy an explicit assumption + QP-RX-04 release criteri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
    [bom-control-card-igbt.csv, bom-control-card-igbt4.csv, bom-control-card-sic4.csv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]
2026-09-26 Rev A.19: round 20 — three rechecks of 00f6252 (F205-F207): TVS alternate to the 7.0 V class + lock, 4XX discharge alternate 470→220 Ω + lock, T-05/T-06 firmware ID, 8.5 V-era figures re-derived at t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
    [bom-control-card-igbt.csv, bom-control-card-igbt4.csv, bom-control-card-sic4.csv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]
2026-09-26 Rev A.20: round 21 — three rechecks of 551c405 (F208): stale 0.29 Ω in gate ㉘ and the QP-RX-04 fixture instruction → 0.37 Ω, last 8.5 V-era figures aligned, Marine sweep cross-references at the curre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
    [bom-control-card-igbt.csv, bom-control-card-igbt4.csv, bom-control-card-sic4.csv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]
2026-09-26 Rev A.21: round 22 — three rechecks of 0ff44d9 (F209) + the layout handoff (F210–F213): every KiCad symbol bound to a footprint in a shipped traction.pretty (45 verbatim KiCad-10 patterns + 18 datash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
    [bom-discharge-igbt4.csv, bom-discharge-sic4.csv, bom-power-igbt.csv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]
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2026-09-27 Rev A.22: round 23 — rechecks of 452de85 (F214–F220), the VESC program (FW-38…FW-46, Traction Tool in Qt) and the "why not done" extension (F221–F239)
    Hardware: the R2R reference isolated at ball A9 (RR2R 10 Ω + 1 µF + 100 nF, S32K39 DS note 8), the SWD header on its
    surface-mount Samtec land with a mounting-technology lock in the library generator, the footprint library declared
    KiCad 10.0.6+ and no longer mirrored into the KiCad 5 sets; the BOM intro follows the SKU; a VREFH window row and VR-34/35.
    Firmware (TI_FW_ID 0x0A0F0015, CAL layout 4, 190 fields / 91 CAL rows, 80 DTCs): FW-37 joint torque solve with a
    postcondition; the VESC gap closure — FW-38 signed field update (Ed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
    [bom-control-card-igbt.csv, bom-control-card-igbt4.csv, bom-control-card-sic4.csv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]
2026-09-27 Rev A.23: round 24 — four rechecks of 4ed0101 (F240–F244): the SDADC reference on its supply node, acquisition freshness, the map's flux slope and the ripple limiter's exact bounds, the temperature l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
    Hardware (F240, no new part): the S32K39 data sheet's SDADC table (Rev. 3 Table 38, in our archive and our own
    extracted-parameters file) requires VREFP within ±25 mV of AVDD; the round-23 disposition had judged the general +100 mV
    note and called the figure absent while the references sat on the FS26 VREF, matched to the SDADC-supply LDO only within
    ±1 %. Every non-R2R reference group (E6/H6 SAR, E10/F13 SDADC) is now on V5A itself with VDDA_SDADC and VDD_HV_A (NXP's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
    [bom-control-card.csv, review-A23-disposition.csv, traction-capbank.kicad_sch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]

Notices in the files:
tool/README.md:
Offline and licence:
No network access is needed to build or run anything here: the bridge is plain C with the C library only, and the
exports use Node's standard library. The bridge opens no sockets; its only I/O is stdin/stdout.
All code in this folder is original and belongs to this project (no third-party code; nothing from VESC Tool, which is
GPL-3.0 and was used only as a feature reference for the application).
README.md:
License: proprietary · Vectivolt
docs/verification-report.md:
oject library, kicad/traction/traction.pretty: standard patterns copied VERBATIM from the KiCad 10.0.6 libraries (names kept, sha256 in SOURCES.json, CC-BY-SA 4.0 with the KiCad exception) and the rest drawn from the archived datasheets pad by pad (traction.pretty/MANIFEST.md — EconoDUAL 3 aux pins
